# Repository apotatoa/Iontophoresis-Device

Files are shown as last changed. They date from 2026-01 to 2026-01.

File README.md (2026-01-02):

# Open Source Iontophoresis Device

## ⚠️ SAFETY WARNING: READ BEFORE BUILDING

> **DANGER:** This project involves the design and construction of a device that applies electrical current to the human body. Improper construction, component failure, or misuse can result in **electric shock, burns, injury, or death**.

* **Galvanic Isolation is mandatory:** Never bypass the isolation barriers designed into this PCB.
* **Battery Power Only:** This device is designed solely for battery operation.
* **Educational Use:** This project is for educational and research purposes only. It is not an FDA-approved medical device.
* **Liability:** The authors and contributors are not responsible for any harm caused by the assembly or use of this device. **Build and use at your own risk.**

---

## Project Overview

This repository contains the complete hardware, firmware, and mechanical design files for a **User-Controlled Iontophoresis Device** intended for the treatment of hyperhidrosis.

The system uses a regulated DC current (typically 0–30mA) applied through water baths to treat excessive sweating of the hands or feet. Unlike simple resistive devices, this project features active closed-loop current regulation, ensuring consistent treatment current regardless of water resistance or skin impedance changes.

To learn more about this project, check out this blog post on maker.io:
> Coming Soon: Link to DigiKey blog post on maker.io

## Key Features

* **Galvanic Isolation:** Physical and electrical separation between the control logic (ESP32) and the high-voltage treatment side using an isolated DC-DC converter (Ag7200) and optocouplers.
* **Active Current Control:** PWM-driven Op-Amp and MOSFET current sink maintains steady current.
* **Automatic Polarity Switching:** Integrated H-Bridge relays automatically reverse polarity halfway through treatment to ensure even effect on both limbs.
* **Safety Fuse:** Hardware-level protection in a quick-blow fuse that physically blocks the current path if it exceeds safety limits (independent of software).

## Repository Structure

```text
Iontophoresis-Device/
├── README.md         # Project documentation and safety warnings
├── 3d/
│   ├── CAD/          # .step files for the enclosure body and lid
│   └── blender/      # .blend files and .mp4 renders for visualization
├── firmware/
│   └── Ionto_Sketch.ino # Arduino source code for the ESP32-S3
└── hardware/
    ├── Ionto.kicad_pro  # KiCad 9.0 Project File
    ├── Ionto.kicad_sch  # Schematic File
    ├── Current_Regulator.kicad_sch    #heirarchal schematic for current regulation 
    ├── H-Bridge.kicad_sch             #heirarchal schematic for H-Bridge
    ├── Ionto.kicad_pcb  # 6-Layer PCB Layout File
    └── jlcpcb/          # Production files (Gerbers, BOM, CPL)
```

## Hardware Design (KiCad)

The PCB is a 6-layer board designed in KiCad 9.0. It utilizes a strict zonal separation layout to maintain safety standards.

* **Dirty Zone (Logic):** ESP32-S3-WROOM-1, USB-C (Programming/Charging), User Controls.
* **Isolation Bridge:** Ag7200 Module (Power) and Optocouplers (Signal).
* **Clean Zone (High Voltage):** Boosted 40V rail, LM358 Op-Amp, IRF540N MOSFET, Relays, and Output Banana Jacks.

### Critical Components
* **MCU:** ESP32-S3 Dev Module
* **Isolation:** Ag7200 (DC-DC), PC817 (Opto)
* **Power:** 11.1V 3S LiPo Battery
* **Current Regulation:** LM358 Op-Amp + IRF540N MOSFET

## Firmware (Arduino/ESP32)

The firmware handles the control loop, user interface, and treatment timing.

### Dependencies
* **Board:** ESP32S3 Dev Module
* **Libraries Required:**
    * `U8g2` (by oliver) - For the OLED Display menu system.
    * `MUIU8g2` - For the menu user interface.
    * `Wire` - Standard I2C library.

### Flashing Instructions
1.  Open `firmware/Ionto_Sketch.ino` in the Arduino IDE.
2.  Install the required libraries via the Library Manager.
3.  Select Board: **ESP32S3 Dev Module**.
4.  Upload to the device.

## Controls

* **Button 1 (Left):** Decrease Value
* **Button 2 (Center):** Increase Value
* **Button 3 (Right):** Enter & Next Field / Start / Stop

## Mechanical (3D & CAD)

The enclosure is designed to be 3D printed.

* **Files:** Located in `3d/CAD/`.
* **Material:** PETG or ABS is recommended for heat resistance and durability, though PLA is sufficient for prototyping.
* **Assembly:** The PCB mounts into the base using M3 screws. The display requires 3x 10.2mm M2 standoff.
* **Note:** Ensure non-conductive washers are used if mounting holes are near copper planes.

## Liability & Disclaimer

This hardware design and software are provided "as is" without warranty of any kind. The user assumes all liability for the assembly, testing, and operation of this device. This device is not certified by any regulatory body (FCC, CE, UL, FDA, etc.).

**By cloning this repository or building this device, you agree that you are solely responsible for your safety and the safety of others.**

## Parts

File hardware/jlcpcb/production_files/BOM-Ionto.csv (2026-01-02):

Comment | Designator | Footprint | LCSC | Quantity
330 | R1 | R_0805_2012Metric_Pad1.20x1.40mm_HandSolder |  | 1
SMAJ58A | D1 | D_SMA |  | 1
10k | R7 | R_0805_2012Metric_Pad1.20x1.40mm_HandSolder |  | 1
100nF | C1 | C_0805_2012Metric_Pad1.18x1.45mm_HandSolder |  | 1
Dec- | SW5 | SW_PUSH-12mm |  | 1
Conn_01x01 | J5 | Banana_Cliff_FCR7350R_S16N-PC_Horizontal |  | 1
LM358DT | U5 | DIP-8_W10.16mm |  | 1
Fuse | 50mA1 | Fuse_1206_3216Metric_Pad1.42x1.75mm_HandSolder |  | 1
2N3904 | Q1 | TO-92_Inline |  | 1
4.7k | R14 | R_0805_2012Metric_Pad1.20x1.40mm_HandSolder |  | 1
10k | R5 | R_0805_2012Metric_Pad1.20x1.40mm_HandSolder |  | 1
Conn_01x02_Pin | J1 | TestPoint_2Pads_Pitch5.08mm_Drill1.3mm |  | 1
1uF | C6 | C_0805_2012Metric_Pad1.18x1.45mm_HandSolder |  | 1
1uF | C11 | C_Elec_5x5.8 |  | 1
10uF/25v | C10 | CP_Elec_8x10 |  | 1
10k | R6 | R_0805_2012Metric_Pad1.20x1.40mm_HandSolder |  | 1
2N3904 | Q2 | TO-92_Inline |  | 1
Inc+ | SW4 | SW_PUSH-12mm |  | 1
4.7uH | L1 | L_7.3x7.3_H4.5 |  | 1
AP63203WU | U2 | TSOT-23-6 |  | 1
.1uF | C12 | C_0805_2012Metric_Pad1.18x1.45mm_HandSolder |  | 1
Conn_01x04_Pin | J2 | PinHeader_1x04_P2.54mm_Vertical |  | 1
22uF | C3 | CP_Elec_5x3 |  | 1
10k | R4 | R_0805_2012Metric_Pad1.20x1.40mm_HandSolder |  | 1
Enter | SW3 | SW_PUSH-12mm |  | 1
Reset | SW2 | SW_Tactile_SKHH_Angled |  | 1
1k | R8 | R_0805_2012Metric_Pad1.20x1.40mm_HandSolder |  | 1
IRF540N | Q3 | TO-220-3_Vertical |  | 1
1uF | C8 | C_0805_2012Metric_Pad1.18x1.45mm_HandSolder |  | 1
1uF | C7 | C_0805_2012Metric_Pad1.18x1.45mm_HandSolder |  | 1
SANYOU_SRD_Form_C | K1 | Relay_SPDT_SANYOU_SRD_Series_Form_C |  | 1
47uF/63v | C9 | CP_Elec_8x10 |  | 1
250k | RV1 | Potentiometer_Bourns_3314G_Vertical |  | 1
22uF | C4 | CP_Elec_5x3 |  | 1
1N4742A/12v/1w | D4 | D_DO-41_SOD81_P10.16mm_Horizontal |  | 1
Buzzer | BZ1 | Buzzer_TDK_PS1240P02BT_D12.2mm_H6.5mm |  | 1
10uF | C2 | C_0805_2012Metric_Pad1.18x1.45mm_HandSolder |  | 1
SANYOU_SRD_Form_C | K2 | Relay_SPDT_SANYOU_SRD_Series_Form_C |  | 1
5.6k/0.5w | R12 | R_Axial_DIN0414_L11.9mm_D4.5mm_P15.24mm_Horizontal |  | 1
1uF | C5 | C_0805_2012Metric_Pad1.18x1.45mm_HandSolder |  | 1
1N4148 | D2 | D_DO-35_SOD27_P7.62mm_Horizontal |  | 1
Conn_01x01 | J4 | Banana_Cliff_FCR7350B_S16N-PC_Horizontal |  | 1
100Ω/1w | R11 | R_Axial_DIN0414_L11.9mm_D4.5mm_P15.24mm_Horizontal |  | 1
ESP32-S3-WROOM-1 | U3 | ESP32-S3-WROOM-1 |  | 1
Ag7200 | U4 | Ag7200 |  | 1
10k | R13 | R_0805_2012Metric_Pad1.20x1.40mm_HandSolder |  | 1
USB_C_Receptacle_USB2.0_14P | J3 | USB_C_Receptacle_XKB_U262-16XN-4BVC11 |  | 1
1k | R10 | R_0805_2012Metric_Pad1.20x1.40mm_HandSolder |  | 1
1N4148 | D3 | D_DO-35_SOD27_P7.62mm_Horizontal |  | 1
SW_Wuerth_450301014042 | SW1 | SW_Slide-03_Wuerth-WS-SLTV_10x2.5x6.4_P2.54mm |  | 1
PC817 | U6 | DIP-4_W7.62mm |  | 1
1k | R9 | R_0805_2012Metric_Pad1.20x1.40mm_HandSolder |  | 1
TestPoint | TP4 | TestPoint_Pad_D2.0mm |  | 1
TestPoint | TP2 | TestPoint_Pad_D2.0mm |  | 1
5.1k | R3 | R_0805_2012Metric_Pad1.20x1.40mm_HandSolder |  | 1
TestPoint | TP11 | TestPoint_Pad_D2.0mm |  | 1
5.1k | R2 | R_0805_2012Metric_Pad1.20x1.40mm_HandSolder |  | 1
TestPoint | TP3 | TestPoint_Pad_D2.0mm |  | 1
TestPoint | TP10 | TestPoint_Pad_D2.0mm |  | 1
TestPoint | TP5 | TestPoint_Pad_D2.0mm |  | 1
TestPoint | TP7 | TestPoint_Pad_D2.0mm |  | 1
TestPoint | TP12 | TestPoint_Pad_D2.0mm |  | 1
TestPoint | TP6 | TestPoint_Pad_D2.0mm |  | 1
TestPoint | TP1 | TestPoint_Pad_D2.0mm |  | 1
TestPoint | TP9 | TestPoint_Pad_D2.0mm |  | 1
TestPoint | TP8 | TestPoint_Pad_D2.0mm |  | 1

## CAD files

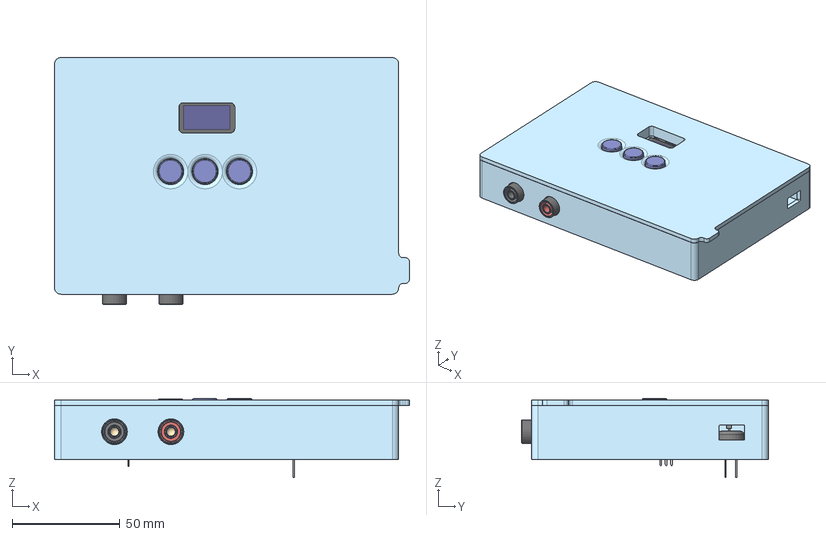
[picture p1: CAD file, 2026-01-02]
3d/CAD/Assembly/Assembly 1.step
165.0 x 114.7 x 36.8 mm
12x12mm Square Actuator Momentary PCB Tactile Switch Cap (1) x 3
(Unsaved) x 8
ESP32-S3-WROOM-1 x 52
D_DO-35_SOD27_P7.62mm_Horizontal x 4
TO-92_Inline x 2
Banana_Cliff_FCR7350R_S16N-PC_Horizontal x 2
C_0805_2012Metric x 7
R_0805_2012Metric x 12
TSOT-23-6
CP_Elec_5x3 x 2
12x12mm Square Actuator Momentary PCB Tactile Switch x 3
CP_Elec_8x10 x 2
Banana_Cliff_FCR7350B_S16N-PC_Horizontal x 2
TO-220-3_Vertical
Ionto_PCB
Relay_SPDT_SANYOU_SRD_Series_Form_C x 2
Fuse_1206_3216Metric
D_SMA
R_Axial_DIN0414_L11.9mm_D4.5mm_P15.24mm_Horizontal x 2
Buzzer_TDK_PS1240P02BT_D12.2mm_H6.5mm
PinHeader_1x04_P2.54mm_Vertical
D_DO-41_SOD81_P10.16mm_Horizontal
DIP-4_W7.62mm
Potentiometer_Bourns_3314G_Vertical
DIP-8_W10.16mm
C_Elec_5x5.8 x 2

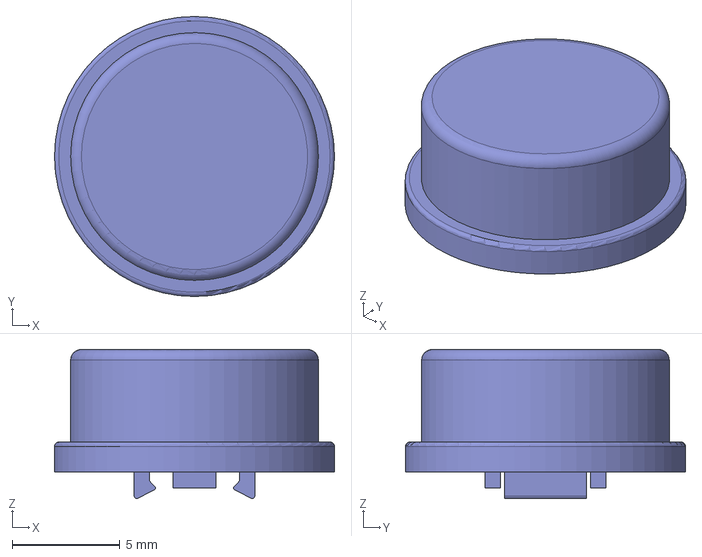
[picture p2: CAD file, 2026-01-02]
3d/CAD/comps/12x12mm Square Actuator Momentary PCB Tactile Switch Cap.step
13.0 x 13.0 x 6.92 mm

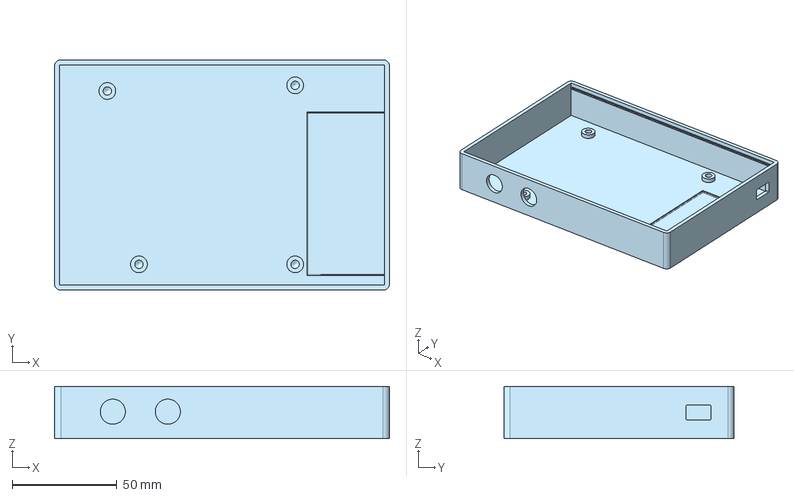
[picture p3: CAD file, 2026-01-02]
3d/CAD/comps/Case.step
160.0 x 110.0 x 25.0 mm

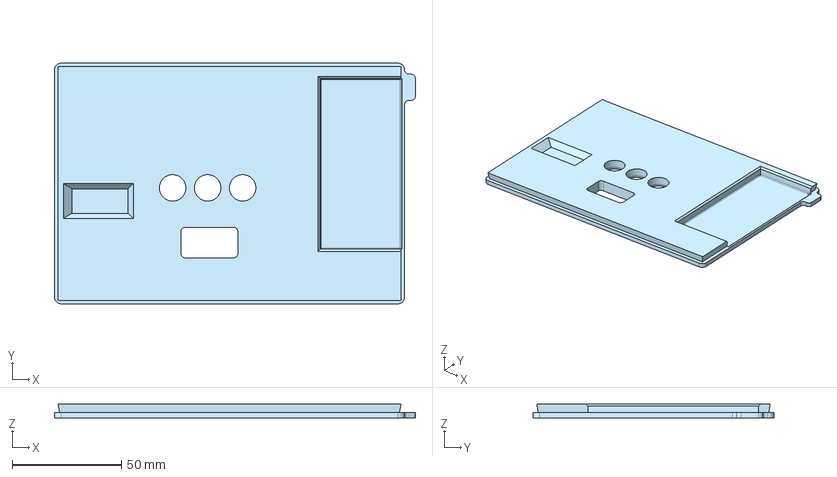
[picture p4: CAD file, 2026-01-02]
3d/CAD/comps/Lid.step
165.0 x 110.0 x 6.50 mm

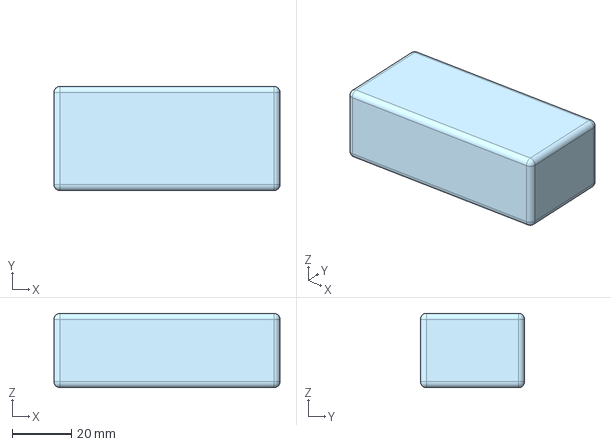
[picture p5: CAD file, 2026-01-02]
3d/CAD/comps/Battery.step
76.0 x 35.0 x 25.0 mm

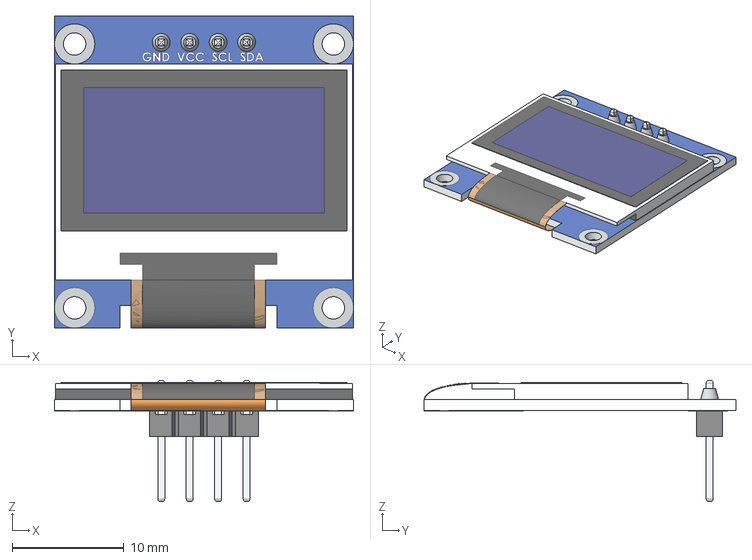
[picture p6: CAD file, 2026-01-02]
3d/CAD/comps/OLED-128x64-0.96.step
26.7 x 27.9 x 10.8 mm

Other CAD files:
3d/blender/Ionto.blend

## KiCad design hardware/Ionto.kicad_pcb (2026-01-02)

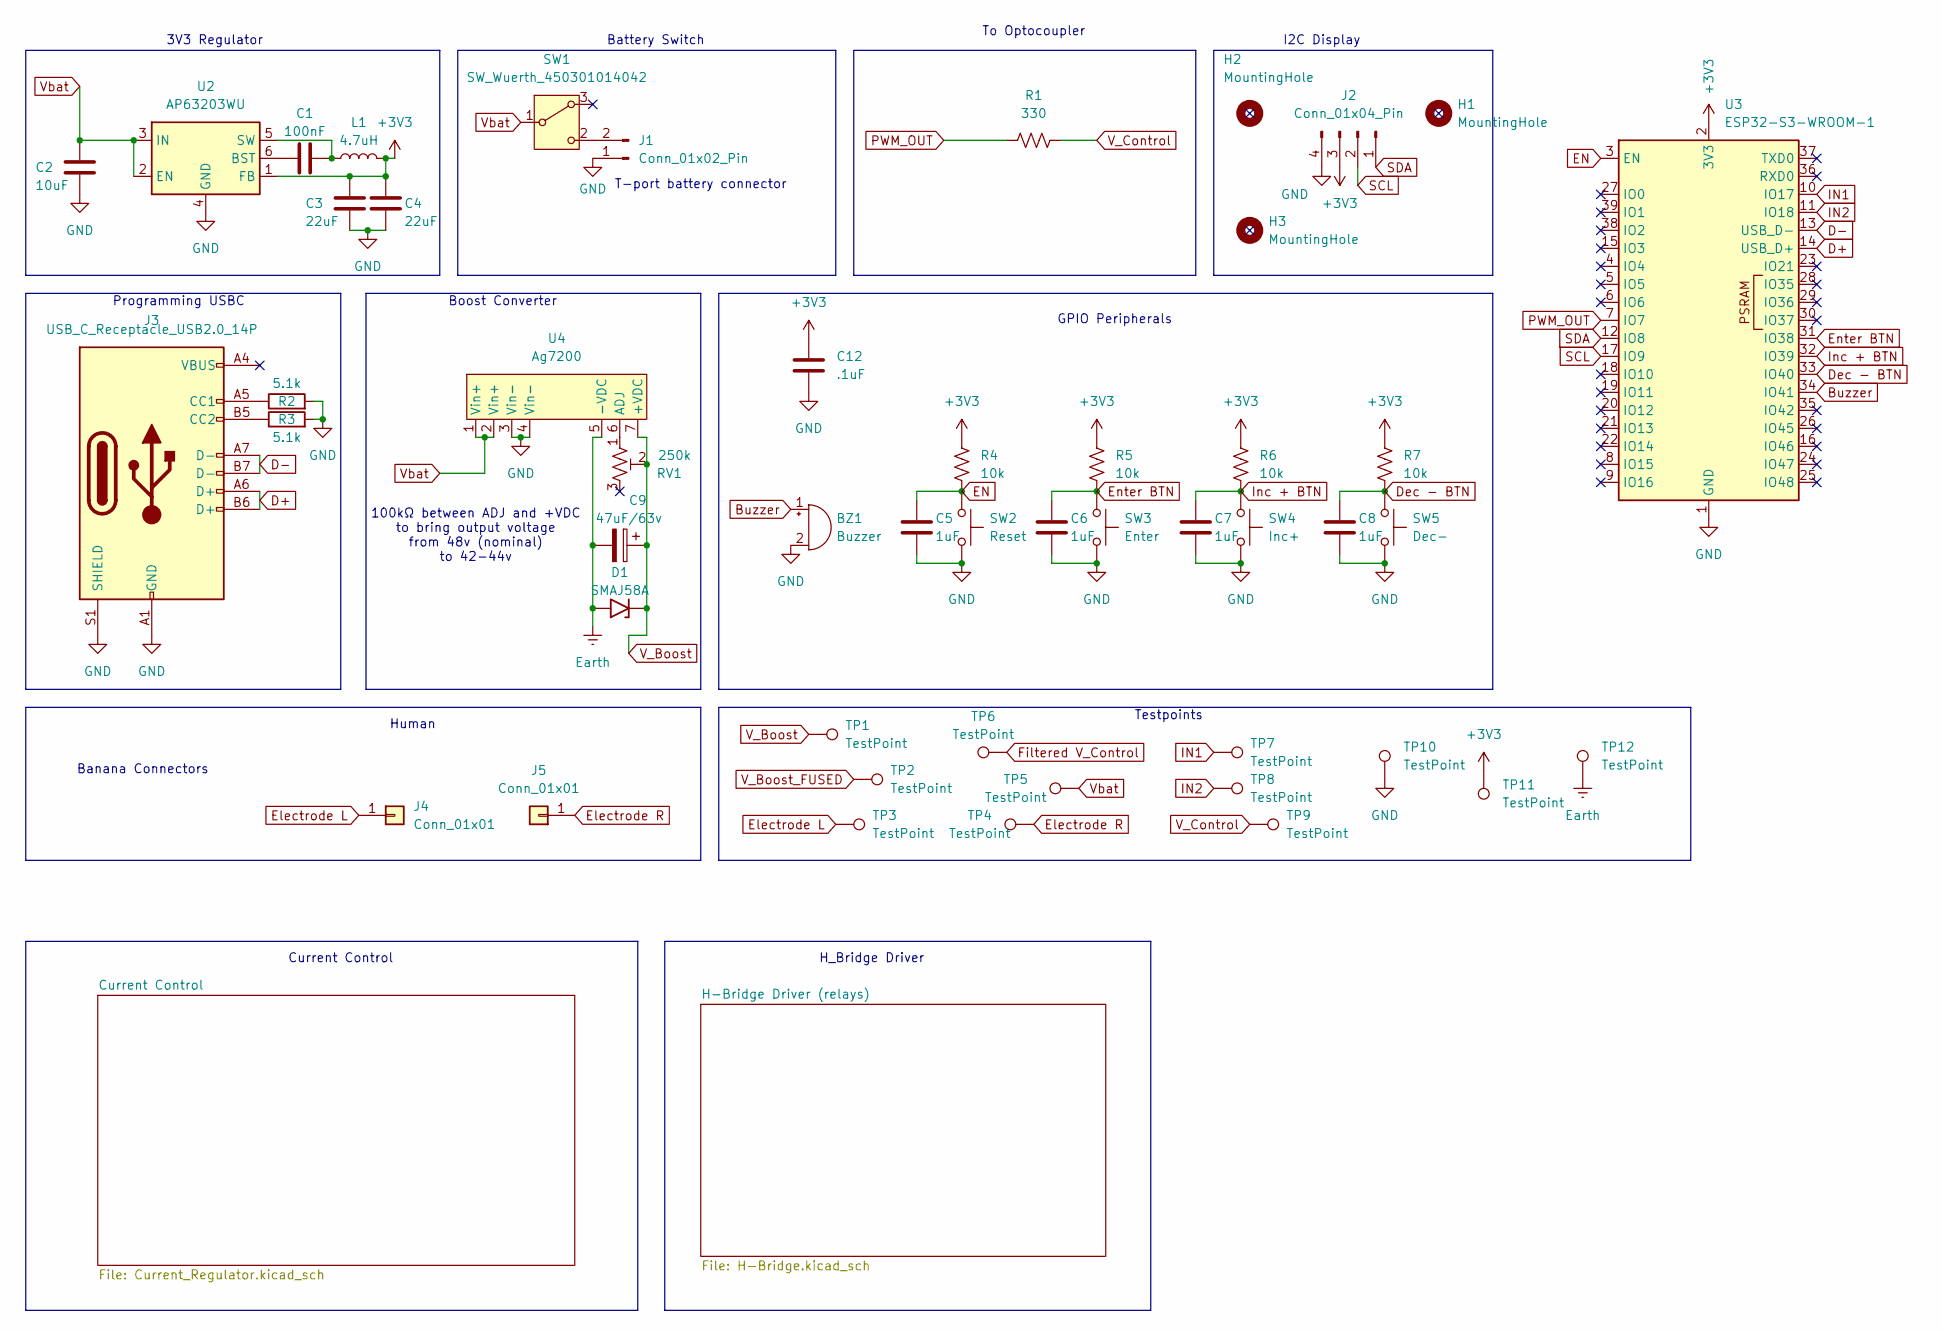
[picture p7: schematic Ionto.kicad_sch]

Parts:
BZ1: Buzzer; Buzzer_TDK_PS1240P02BT_D12.2mm_H6.5mm
C1: 100nF; C_0805_2012Metric_Pad1.18x1.45mm_HandSolder
C2: 10uF; C_0805_2012Metric_Pad1.18x1.45mm_HandSolder
C3, C4: 22uF; CP_Elec_5x3
C5, C6, C7, C8: 1uF; C_0805_2012Metric_Pad1.18x1.45mm_HandSolder
C9: 47uF/63v; CP_Elec_8x10
C12: .1uF; C_0805_2012Metric_Pad1.18x1.45mm_HandSolder
D1: SMAJ58A; D_SMA
H1, H2, H3: MountingHole; MountingHole_2.2mm_M2_Pad_TopBottom
J1: Conn_01x02_Pin; TestPoint_2Pads_Pitch5.08mm_Drill1.3mm
J2: Conn_01x04_Pin; PinHeader_1x04_P2.54mm_Vertical
J3: USB_C_Receptacle_USB2.0_14P; USB_C_Receptacle_XKB_U262-16XN-4BVC11
J4: Conn_01x01; Banana_Cliff_FCR7350B_S16N-PC_Horizontal
J5: Conn_01x01; Banana_Cliff_FCR7350R_S16N-PC_Horizontal
L1: 4.7uH; L_7.3x7.3_H4.5
R1: 330; R_0805_2012Metric_Pad1.20x1.40mm_HandSolder
R2, R3: 5.1k; R_0805_2012Metric_Pad1.20x1.40mm_HandSolder
R4, R5, R6, R7: 10k; R_0805_2012Metric_Pad1.20x1.40mm_HandSolder
RV1: 250k; Potentiometer_Bourns_3314G_Vertical
SW1: SW_Wuerth_450301014042; SW_Slide-03_Wuerth-WS-SLTV_10x2.5x6.4_P2.54mm
SW2: Reset; SW_Tactile_SKHH_Angled
SW3: Enter; SW_PUSH-12mm
SW4: Inc+; SW_PUSH-12mm
SW5: Dec-; SW_PUSH-12mm
TP1, TP2, TP3, TP4, TP5, TP6, TP7, TP8, TP9, TP10, TP11, TP12: TestPoint; TestPoint_Pad_D2.0mm
U2: AP63203WU; TSOT-23-6
U3: ESP32-S3-WROOM-1
U4: Ag7200

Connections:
+3V3: C3.1, C4.1, C12.1, J2.3, L1.2, R4.1, R5.1, R6.1, R7.1, TP11.1, U2.1 (FB), U3.2 (3V3)
Buzzer: BZ1.1 (+), U3.34 (IO41)
D+: J3.A6 (D+), J3.B6 (D+), U3.14 (USB_D+)
D-: J3.A7 (D-), J3.B7 (D-), U3.13 (USB_D-)
Dec - BTN: C8.1, R7.2, SW5.1, U3.33 (IO40)
EN: C5.1, R4.2, SW2.1, U3.3 (EN)
Earth: C9.2, D1.2 (A2), TP12.1, U4.5 (-VDC); also elsewhere on the board
Electrode L: J4.1, TP3.1; also elsewhere on the board
Electrode R: J5.1, TP4.1; also elsewhere on the board
Enter BTN: C6.1, R5.2, SW3.1, U3.31 (IO38)
Filtered V_Control: TP6.1; also elsewhere on the board
GND: BZ1.2 (-), C2.2, C3.2, C4.2, C5.2, C6.2, C7.2, C8.2, C12.2, J1.1, J2.4, J3.A1 (GND), J3.A12 (GND), J3.B1 (GND), J3.B12 (GND), J3.S1 (SHIELD), R2.2, R3.2, SW2.2, SW3.2, SW4.2, SW5.2, TP10.1, U2.4 (GND), U3.1 (GND), U3.40 (GND), U3.41 (GND), U4.3 (Vin-), U4.4 (Vin-); also elsewhere on the board
IN1: TP7.1, U3.10 (IO17); also elsewhere on the board
IN2: TP8.1, U3.11 (IO18); also elsewhere on the board
Inc + BTN: C7.1, R6.2, SW4.1, U3.32 (IO39)
unnamed: J1.2, SW1.2 (C)
unnamed: J3.A5 (CC1), R2.1
unnamed: J3.B5 (CC2), R3.1
unnamed: C1.1, U2.6 (BST)
unnamed: C1.2, L1.1, U2.5 (SW)
unnamed: RV1.1, U4.6 (ADJ)
PWM_OUT: R1.1, U3.7 (IO7)
SCL: J2.2, U3.17 (IO9)
SDA: J2.1, U3.12 (IO8)
V_Boost: C9.1, D1.1 (A1), RV1.2, TP1.1, U4.7 (+VDC); also elsewhere on the board
V_Boost_FUSED: TP2.1; also elsewhere on the board
V_Control: R1.2, TP9.1; also elsewhere on the board
Vbat: C2.1, SW1.1 (B), TP5.1, U2.2 (EN), U2.3 (IN), U4.1 (Vin+), U4.2 (Vin+); also elsewhere on the board

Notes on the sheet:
To Optocoupler
3V3 Regulator
Banana Connectors
Testpoints
Programming USBC
Current Control
T-port battery connector
100kΩ between ADJ and +VDC to bring output voltage from 48v (nominal) to 42-44v
H_Bridge Driver
I2C Display
GPIO Peripherals
Battery Switch
Human
Boost Converter

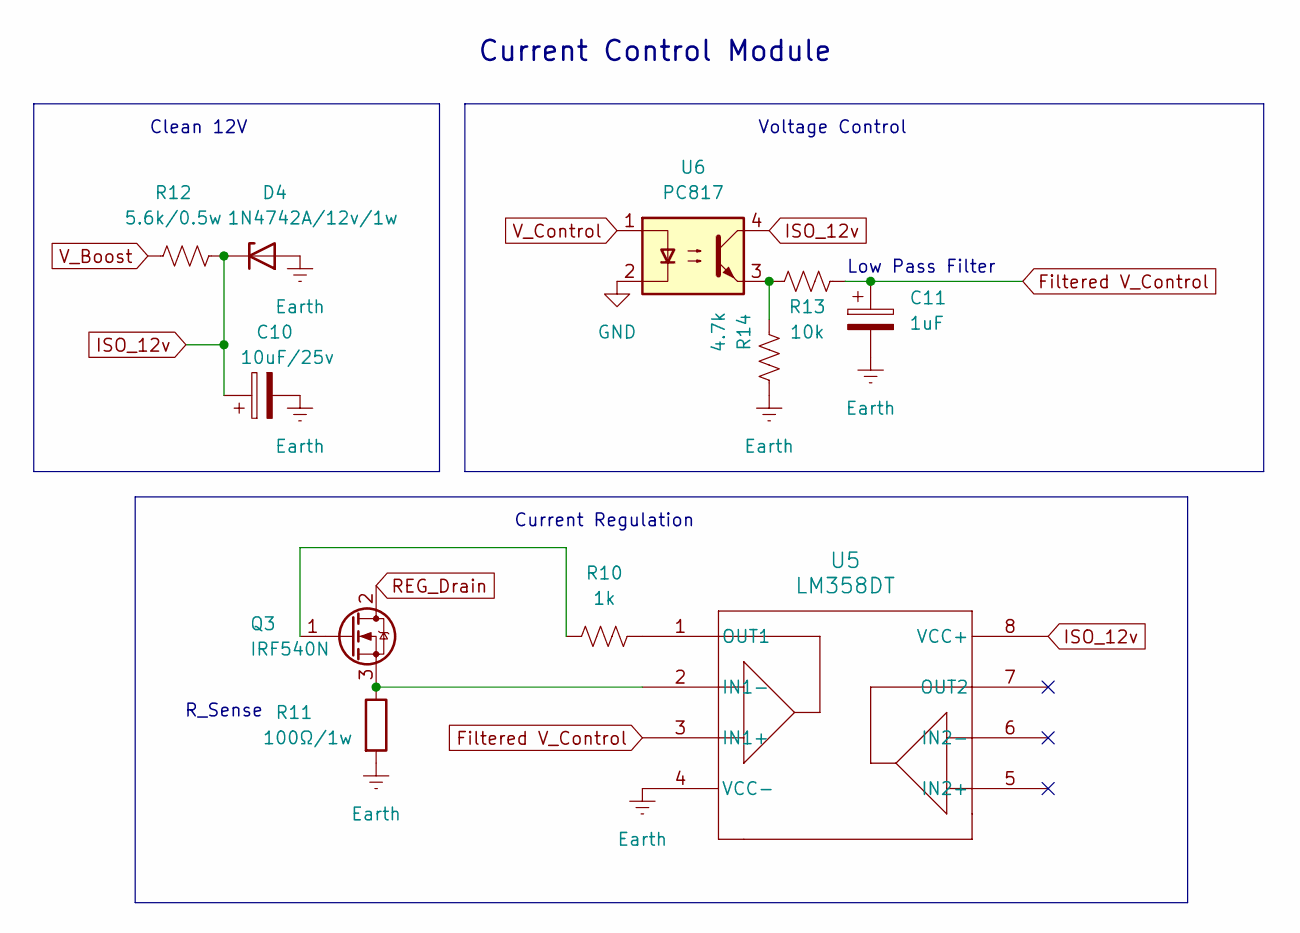
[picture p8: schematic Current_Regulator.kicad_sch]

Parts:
C10: 10uF/25v; CP_Elec_8x10
C11: 1uF; C_Elec_5x5.8
D4: 1N4742A/12v/1w; D_DO-41_SOD81_P10.16mm_Horizontal
Q3: IRF540N; TO-220-3_Vertical
R10: 1k; R_0805_2012Metric_Pad1.20x1.40mm_HandSolder
R11: 100Ω/1w; R_Axial_DIN0414_L11.9mm_D4.5mm_P15.24mm_Horizontal
R12: 5.6k/0.5w; R_Axial_DIN0414_L11.9mm_D4.5mm_P15.24mm_Horizontal
R13: 10k; R_0805_2012Metric_Pad1.20x1.40mm_HandSolder
R14: 4.7k; R_0805_2012Metric_Pad1.20x1.40mm_HandSolder
U5: LM358DT; DIP-8_W10.16mm
U6: PC817; DIP-4_W7.62mm

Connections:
Earth: C10.2, C11.2, D4.2 (A), R11.2, R14.1, U5.4 (VCC-); also elsewhere on the board
Filtered V_Control: C11.1, R13.1, U5.3 (IN1+); also elsewhere on the board
GND: U6.2; also elsewhere on the board
ISO_12v: C10.1, D4.1 (K), R12.2, U5.8 (VCC+), U6.4
unnamed: Q3.1 (G), R10.1
unnamed: Q3.3 (S), R11.1, U5.2 (IN1-)
unnamed: R13.2, R14.2, U6.3
unnamed: R10.2, U5.1 (OUT1)
REG_Drain: Q3.2 (D); also elsewhere on the board
V_Boost: R12.1; also elsewhere on the board
V_Control: U6.1; also elsewhere on the board

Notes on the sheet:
Current Regulation
Clean 12V
Current Control Module
Voltage Control
Low Pass Filter
R_Sense

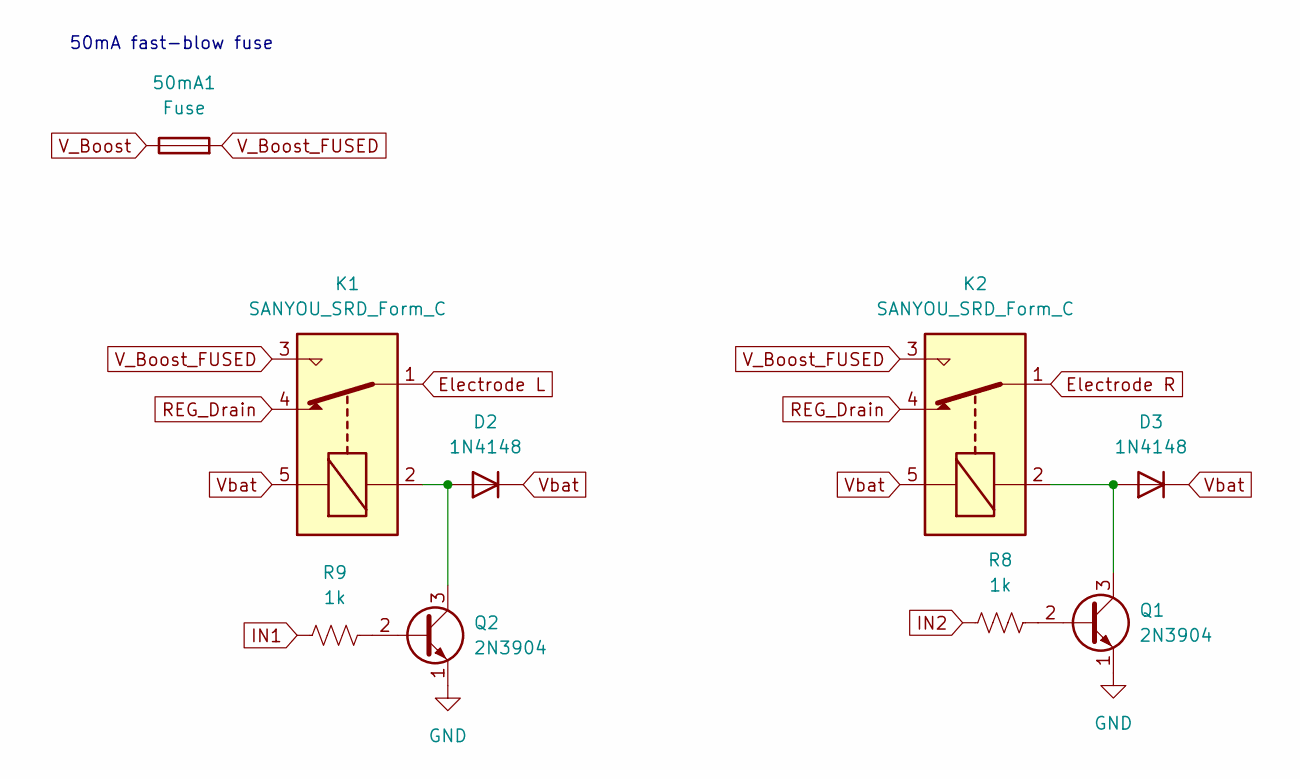
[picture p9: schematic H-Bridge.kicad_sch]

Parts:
50mA1: Fuse; Fuse_1206_3216Metric_Pad1.42x1.75mm_HandSolder
D2, D3: 1N4148; D_DO-35_SOD27_P7.62mm_Horizontal
K1, K2: SANYOU_SRD_Form_C; Relay_SPDT_SANYOU_SRD_Series_Form_C
Q1, Q2: 2N3904; TO-92_Inline
R8, R9: 1k; R_0805_2012Metric_Pad1.20x1.40mm_HandSolder

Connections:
Electrode L: K1.1; also elsewhere on the board
Electrode R: K2.1; also elsewhere on the board
GND: Q1.1 (E), Q2.1 (E); also elsewhere on the board
IN1: R9.1; also elsewhere on the board
IN2: R8.1; also elsewhere on the board
unnamed: D2.2 (A), K1.2, Q2.3 (C)
unnamed: D3.2 (A), K2.2, Q1.3 (C)
unnamed: Q1.2 (B), R8.2
unnamed: Q2.2 (B), R9.2
REG_Drain: K1.4, K2.4; also elsewhere on the board
V_Boost: 50mA1.1; also elsewhere on the board
V_Boost_FUSED: 50mA1.2, K1.3, K2.3; also elsewhere on the board
Vbat: D2.1 (K), D3.1 (K), K1.5, K2.5; also elsewhere on the board

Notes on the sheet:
50mA fast-blow fuse

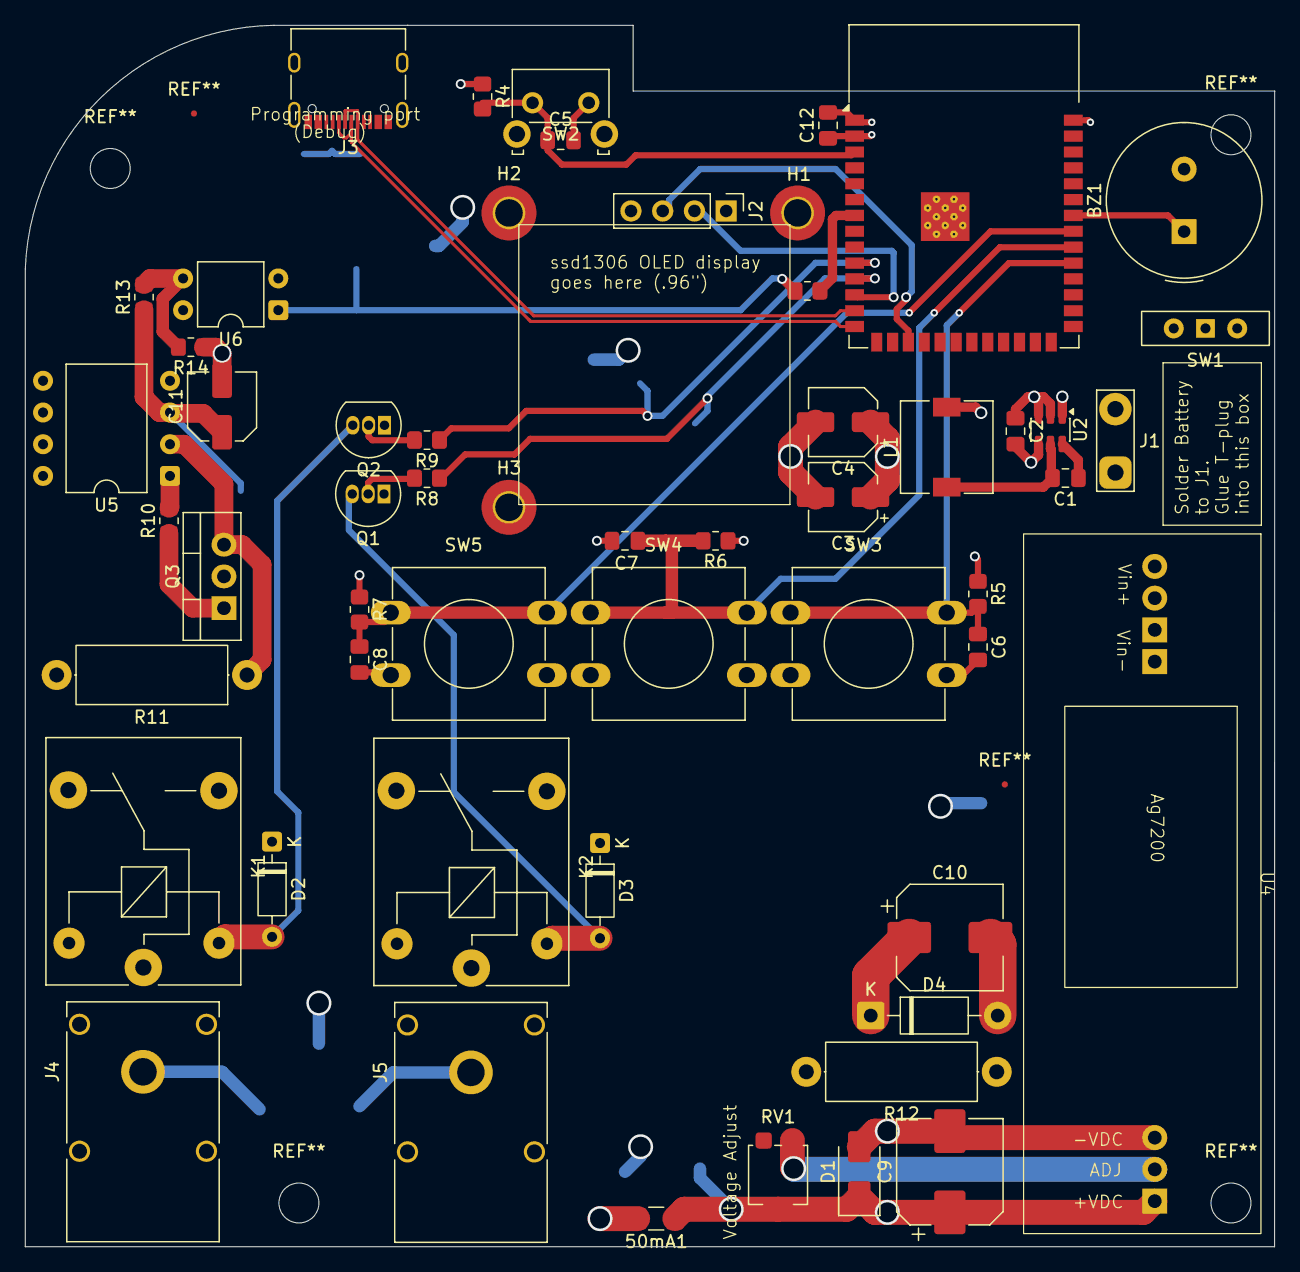
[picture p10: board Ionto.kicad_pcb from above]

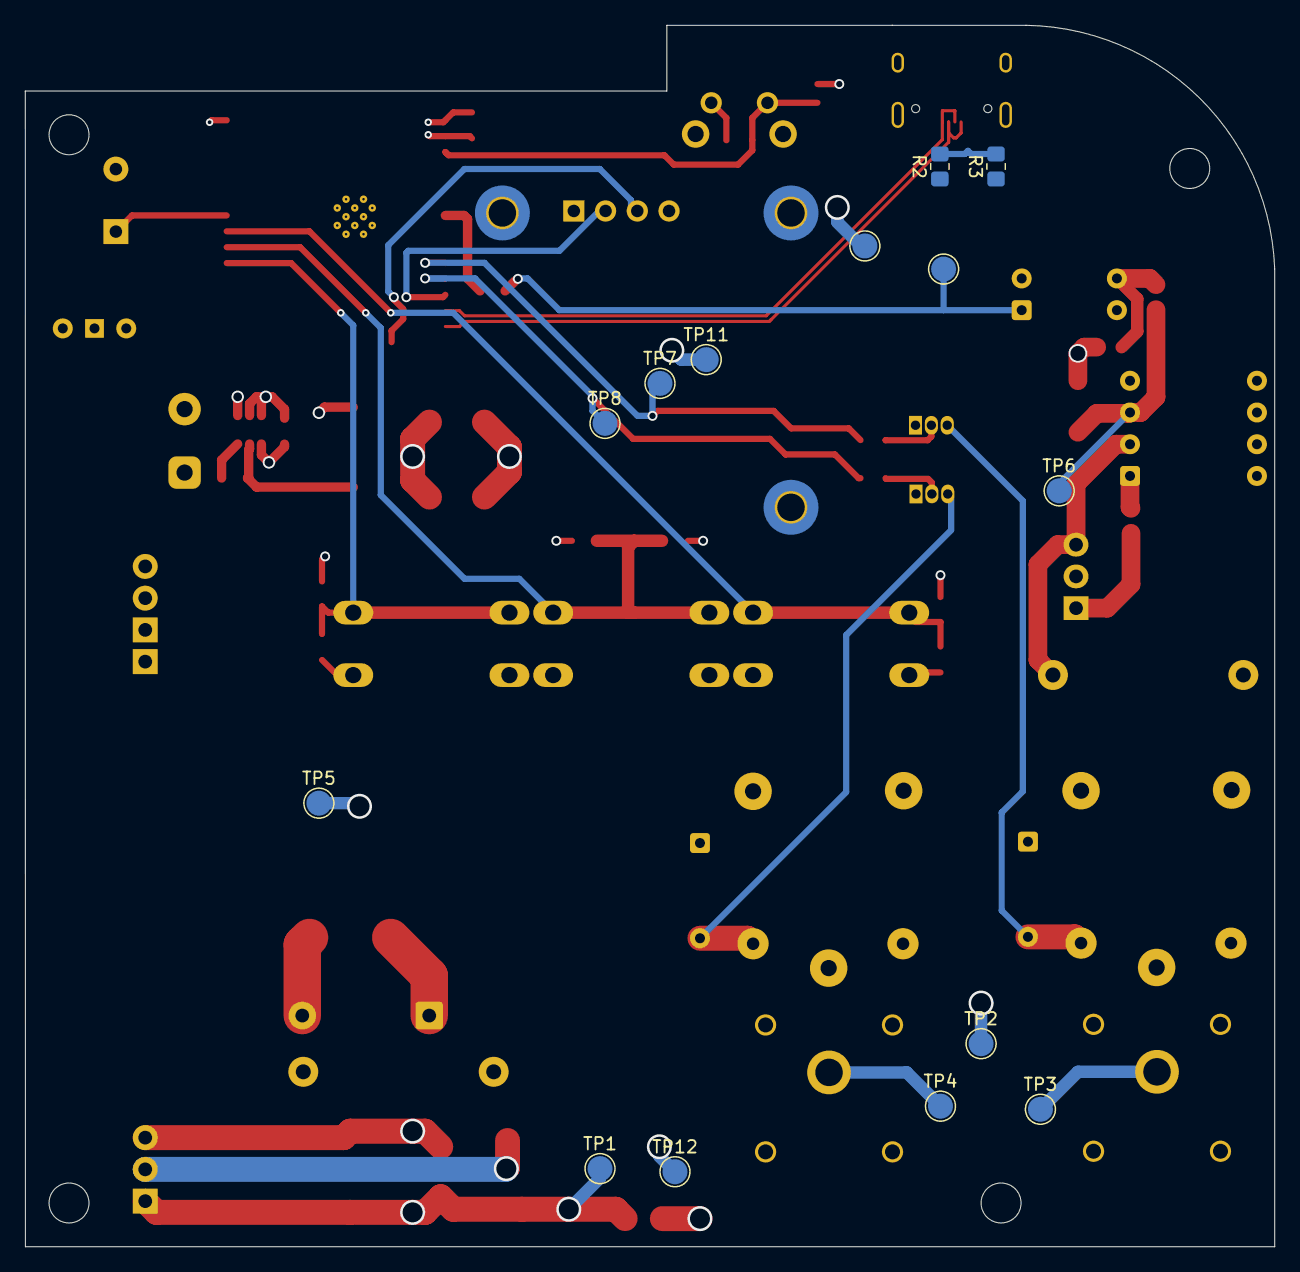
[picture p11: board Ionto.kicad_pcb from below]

Board: 6 copper layers, 100.0 x 97.8 mm, 69 parts (14 on the bottom side), 38 nets.

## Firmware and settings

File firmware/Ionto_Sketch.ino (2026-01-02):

#include <Arduino.h>
#include <Wire.h>
#include <U8g2lib.h>
#include <MUIU8g2.h>

// Pin Definitions

// OLED Display (I2C)
U8G2_SSD1306_128X64_NONAME_1_HW_I2C u8g2(U8G2_R0, U8X8_PIN_NONE, /*scl=*/9, /*sda=*/8);

// Current Control (PWM to RC Filter -> Op-Amp)
const int CURRENT_CONTROL_PIN = 17; // GPIO 17 will output PWM for current magnitude

// H-Bridge Direction Control (Binary HIGH/LOW)
const int DRV_IN1_PIN = 39;
const int DRV_IN2_PIN = 45;

// Button Inputs
const int BUTTON_ENTER_PIN = 40;
const int BUTTON_INCREASE_PIN = 42;
const int BUTTON_DECREASE_PIN = 41;

// Buzzer Output
const int BUZZER_PIN = 5;

// PWM Configuration for the Current Control Pin
const int PWM_FREQUENCY = 25000;    // 25 kHz is great for smooth RC filtering
const int PWM_RESOLUTION_BITS = 8;  // 0-255 duty cycle range

// Global State Variables

// User Input Values 
uint8_t input_minutes = 0;
uint8_t input_seconds = 0;
uint8_t current_mA = 0; // The target current in milliamps (0-30mA)

// Treatment State 
bool treatment_active = false;
uint8_t direction = 0; // 0 for <-- (IN2 HIGH), 1 for --> (IN1 HIGH)
const char* direction_labels[] = { "<--", "-->" };

// Timer State 
uint32_t total_seconds_set = 0;
uint32_t elapsed_seconds = 0;
uint32_t last_tick_ms = 0;
uint8_t display_minutes = 0;
uint8_t display_seconds = 0;

// UI & Menu State 
MUIU8G2 mui;
uint8_t mui_exit_button_var = 0;
bool trigger_treatment_screen = false;
bool auto_return_to_menu = false;
bool countdown_finished_logged = false;
uint8_t redraw_menu = 1;
uint8_t current_field_index = 0; // Tracks which field is active: 0=MM, 1=SS, 2=CU, 3=OK

// MUI Setup

muif_t muif_list[] = {
  MUIF_U8G2_FONT_STYLE(0, u8g2_font_helvR08_tr),
  MUIF_U8G2_U8_MIN_MAX("MM", &input_minutes, 0, 20, mui_u8g2_u8_min_max_wm_mse_pi),
  MUIF_U8G2_U8_MIN_MAX("SS", &input_seconds, 0, 59, mui_u8g2_u8_min_max_wm_mse_pi),
  MUIF_U8G2_U8_MIN_MAX("CU", &current_mA, 0, 30, mui_u8g2_u8_min_max_wm_mse_pi),
  MUIF_VARIABLE("OK", &mui_exit_button_var, mui_u8g2_btn_exit_wm_fi),
  MUIF_LABEL(mui_u8g2_draw_text)
};

fds_t fds_data[] MUI_PROGMEM =
  MUI_FORM(1)
  MUI_STYLE(0)
  MUI_LABEL(5, 0, "------")
  MUI_LABEL(5, 8, "Minutes:")
  MUI_XY("MM", 64, 8)
  MUI_LABEL(96, 8, ":")
  MUI_XY("SS", 102, 8)
  MUI_LABEL(5, 24, "Current:")
  MUI_XY("CU", 80, 24)
  MUI_LABEL(5, 56, "------")
  MUI_XYT("OK", 110, 56, " OK ");

// Hardware Control 

/**
 * @brief Sets the current magnitude by adjusting the PWM duty cycle on the control pin.
 * This PWM signal is intended to be smoothed by an external RC filter.
 */
void set_current_level() {
  if (!treatment_active) {
    ledcWrite(CURRENT_CONTROL_PIN, 0); // Safety: ensure PWM is off if treatment is not active
    return;
  }
  // Map the desired current (0-30mA) to a PWM duty cycle (0-255)
  uint8_t duty_cycle = map(current_mA, 0, 30, 0, 255);
  ledcWrite(CURRENT_CONTROL_PIN, duty_cycle);
}

/**
 * @brief Sets the H-Bridge direction using simple binary logic.
 * IN1 HIGH, IN2 LOW = Direction 1 (-->)
 * IN1 LOW, IN2 HIGH = Direction 0 (<--)
 */
void set_h_bridge_direction() {
  if (direction == 1) { // Forward -->
    digitalWrite(DRV_IN2_PIN, LOW);
    digitalWrite(DRV_IN1_PIN, HIGH);
  } else { // Backward <--
    digitalWrite(DRV_IN1_PIN, LOW);
    digitalWrite(DRV_IN2_PIN, HIGH);
  }
}

/**
 * @brief Safely stops all treatment output. Sets current to 0 and disables H-Bridge.
 */
void stop_treatment_output() {
  ledcWrite(CURRENT_CONTROL_PIN, 0);
  digitalWrite(DRV_IN1_PIN, LOW);
  digitalWrite(DRV_IN2_PIN, LOW);
  Serial.println("Treatment Output STOPPED.");
}

/**
 * @brief Produces a series of beeps on the buzzer.
 * @param n Number of beeps.
 * @param t Duration of each beep in milliseconds.
 */
void beep(int n, int t) {
  for (int i = 0; i < n; i++) {
    digitalWrite(BUZZER_PIN, HIGH);
    delay(t);
    digitalWrite(BUZZER_PIN, LOW);
    delay(t / 2);
  }
}

// UI and Timers 

void draw_menu() {
  if (!redraw_menu) return;
  u8g2.firstPage();
  do { mui.draw(); } while (u8g2.nextPage());
  redraw_menu = 0;
}

void handle_timer_tick() {
  if (!treatment_active) return;

  // Handle case where timer finishes
  if (elapsed_seconds >= total_seconds_set && total_seconds_set > 0) {
    if (!countdown_finished_logged) {
      Serial.println("Countdown Finished. Returning to menu.");
      countdown_finished_logged = true;
      auto_return_to_menu = true;
      beep(3, 50);
    }
    return;
  }

  // Update timer every second
  if (millis() - last_tick_ms >= 1000) {
    last_tick_ms = millis();
    elapsed_seconds++;

    // Switch direction halfway through the timer
    if (total_seconds_set > 0 && elapsed_seconds == total_seconds_set / 2) {
      direction = (direction == 0) ? 1 : 0; // Toggle direction
      Serial.printf("Direction auto-switched to %s\n", direction_labels[direction]);
    }

    uint32_t remaining_seconds = total_seconds_set - elapsed_seconds;
    display_minutes = remaining_seconds / 60;
    display_seconds = remaining_seconds % 60;
  }
}

void draw_treatment_screen() {
  handle_timer_tick();
  char buf[32];
  u8g2.setFont(u8g2_font_helvR08_tr);
  u8g2.firstPage();
  do {
    snprintf(buf, sizeof(buf), "Time %02u:%02u", display_minutes, display_seconds);
    u8g2.drawStr(0, 12, buf);
    snprintf(buf, sizeof(buf), "Cur  %2u mA", current_mA);
    u8g2.drawStr(0, 28, buf);
    u8g2.drawStr(0, 44, direction_labels[direction]);
  } while (u8g2.nextPage());
}

// SETUP 

void setup() {
  Serial.begin(115200);
  Serial.println("\nIontophoresis Controller Initializing...");

  // Configure Inputs
  pinMode(BUTTON_ENTER_PIN, INPUT_PULLUP);
  pinMode(BUTTON_INCREASE_PIN, INPUT_PULLUP);
  pinMode(BUTTON_DECREASE_PIN, INPUT_PULLUP);

  // Configure Outputs
  pinMode(BUZZER_PIN, OUTPUT);
  pinMode(DRV_IN1_PIN, OUTPUT);
  pinMode(DRV_IN2_PIN, OUTPUT);

  // Configure PWM for Current Control
  ledcAttach(CURRENT_CONTROL_PIN, PWM_FREQUENCY, PWM_RESOLUTION_BITS);
  
  // Ensure all outputs are off at startup
  stop_treatment_output();

  // Initialize UI
  u8g2.begin(BUTTON_ENTER_PIN, BUTTON_INCREASE_PIN, BUTTON_DECREASE_PIN, U8X8_PIN_NONE, U8X8_PIN_NONE, U8X8_PIN_NONE);
  mui.begin(u8g2, fds_data, muif_list, sizeof(muif_list) / sizeof(muif_t));
  mui.gotoForm(1, 0);
  current_field_index = 0; // Start at the first field
  Serial.println("Setup complete. Main menu active.");

  beep(1, 10);
}


// MAIN 

void loop() {
  if (mui.isFormActive()) {
    handle_menu_input();
    draw_menu();
  } else {
    if (trigger_treatment_screen) {
      setup_treatment_session();
      trigger_treatment_screen = false;
    }

    if (treatment_active) {
      handle_treatment_input();
      set_h_bridge_direction();
      set_current_level();
      draw_treatment_screen();

      if (auto_return_to_menu) {
        treatment_active = false;
        stop_treatment_output();
      }
    } else {
      return_to_main_menu();
    }
  }
}

// Helper Functions

/**
 * @brief Handles button presses.
 * +/- increases/decreases the value of the current field.
 * Enter confirms and moves to the next field.
 */
void handle_menu_input() {
  uint8_t event = u8g2.getMenuEvent();
  if (event) {
    redraw_menu = 1;
    switch (event) {
      case U8X8_MSG_GPIO_MENU_NEXT: // Increase button (+)
        if (current_field_index == 0 && input_minutes < 20) input_minutes++;
        else if (current_field_index == 1 && input_seconds < 59) input_seconds++;
        else if (current_field_index == 2 && current_mA < 30) current_mA++;
        break;

      case U8X8_MSG_GPIO_MENU_PREV: // Decrease button (-)
        if (current_field_index == 0 && input_minutes > 0) input_minutes--;
        else if (current_field_index == 1 && input_seconds > 0) input_seconds--;
        else if (current_field_index == 2 && current_mA > 0) current_mA--;
        break;

      case U8X8_MSG_GPIO_MENU_SELECT: // Enter button
        if (current_field_index < 3) {
          // Move to the next field
          current_field_index++;
          mui.nextField();
        } else {
          // We are on the "OK" button, so start the treatment
          Serial.println("OK pressed: Starting treatment setup...");
          trigger_treatment_screen = true;
          mui_exit_button_var = 1; // This signals MUI to exit the form
          mui.sendSelect();
          mui.leaveForm();
        }
        break;
    }
  }
}


/**
 * @brief Handles button presses during the active treatment session.
 */
void handle_treatment_input() {
  static unsigned long last_button_time = 0;
  const unsigned long button_debounce = 200;

  if (millis() - last_button_time > button_debounce) {
    if (digitalRead(BUTTON_INCREASE_PIN) == LOW) {
      if (current_mA < 30) current_mA++;
      last_button_time = millis();
    }
    if (digitalRead(BUTTON_DECREASE_PIN) == LOW) {
      if (current_mA > 0) current_mA--;
      last_button_time = millis();
    }
    if (digitalRead(BUTTON_ENTER_PIN) == LOW) {
      Serial.println("Enter button pressed during treatment. Stopping session.");
      auto_return_to_menu = true; // Signal to stop and return
      last_button_time = millis();
    }
  }
}

/**
 * @brief Prepares all state variables for the start of a new treatment session.
 */
void setup_treatment_session() {
  total_seconds_set = (uint32_t)input_minutes * 60 + input_seconds;
  elapsed_seconds = 0;
  last_tick_ms = millis();
  direction = 0; // Always start with the first direction
  display_minutes = input_minutes;
  display_seconds = input_seconds;
  
  auto_return_to_menu = false;
  countdown_finished_logged = false;

  if (total_seconds_set == 0) {
    Serial.println("Timer is 00:00. Treatment will not start.");
    treatment_active = false;
  } else {
    treatment_active = true;
    Serial.printf("=== Treatment Started: %02u:%02u, Current: %u mA ===\n", display_minutes, display_seconds, current_mA);
  }
}

/**
 * @brief Resets state and returns the UI to the main menu form.
 */
void return_to_main_menu() {
  Serial.println("Returning to main menu...");
  stop_treatment_output();

  input_minutes = 0;
  input_seconds = 0;
  current_mA = 0;
  mui_exit_button_var = 0;
  current_field_index = 0; // Reset field index for the next run
  
  mui.gotoForm(1, 0); 
  redraw_menu = 1;
}
